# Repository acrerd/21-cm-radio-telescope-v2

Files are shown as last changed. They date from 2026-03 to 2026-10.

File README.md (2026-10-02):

# SRT Motor Driver

A complete control system for a Small Radio Telescope (SRT) for 21cm hydrogen line observations at Acre Road Observatory, Glasgow.

## System Overview

The system consists of four integrated components:

1. **Arduino Due** - Low-level motor control, position tracking, limit switches, current sensing
2. **WT32-ETH01** - Network interface (Ethernet + WiFi), web UI, Stellarium integration, RA/Dec to Alt/Az coordinate transforms
3. **H1 Receiver** - GNU Radio SDR application for 21cm hydrogen line data acquisition
4. **Observation Scheduler** - Web-based scheduler that coordinates telescope pointing and data recording

```
+------------------+     +----------------------+
|   Stellarium     |     |  Observation         |
|   (TCP:10001)    |     |  Scheduler           |
+--------+---------+     |  (HTTP:5000)         |
         |               |                      |
         |               |  - Schedule obs      |
         |               |  - Point telescope   |
         |               |  - Start/stop SDR    |
         |               +----------+-----------+
         |                          |
         |    HTTP API              | Subprocess
         |    (point telescope)     | (start receiver)
         |                          |
+--------+----------+      +--------+-----------+
|                   |      |                    |
|   WT32-ETH01      |      |   H1 Receiver      |
|    Controller     |      |   (GNU Radio)      |
|                   |      |                    |
|  - Ethernet/WiFi  |      |  - Ettus B200 SDR  |
|  - Web UI (:80)   |      |  - FFT processing  |
|  - Coord convert  |      |  - HDF5 output     |
|  - NTP time sync  |      |  - Live display    |
+--------+----------+      +--------------------+
         |
    UART (Serial)
         |
+--------+----------+
|                   |
|   Arduino Due     |
|                   |
|  - Motor PWM      |
|  - Encoders       |
|  - Limit switches |
|  - Current sense  |
+--------+----------+
         |
    Motors/Mount
         |
+--------+----------+
|                   |
|   3.0m Dish       |
|   1420 MHz Feed   |
|                   |
+-------------------+
```

### Data Flow

1. **Scheduling**: User creates observation schedule via web UI (target, time, duration, integration time); the receiver's tuning is fixed, not set per observation
2. **Telescope Control**: At scheduled time, scheduler sends HTTP request to ESP32 to point telescope
3. **Coordinate Conversion**: ESP32 converts RA/Dec or Galactic coordinates to Alt/Az
4. **Motor Control**: ESP32 sends target to Arduino Due, which drives motors to position
5. **Data Acquisition**: Scheduler launches GNU Radio receiver to capture 21cm spectrum data
6. **Storage**: Integrated spectra (or, for the pulsar, millisecond band power) saved to HDF5 files with timestamps and metadata

## Hardware

### Arduino Due
- **Microcontroller:** Arduino Due (ARM Cortex-M3)
- **Motors:** DC motors with H-bridge drivers
- **Position sensing:** Reed switch encoders (0.5° resolution)
- **Current sensing:** ACS712 hall-effect sensors
- **Limit switches:** Altitude ~0°, Azimuth ~0° and ~355°

### WT32-ETH01

- ESP32 module with built-in LAN8720 Ethernet PHY
- Native 100 Mbps Ethernet (RJ45 connector)
- WiFi 802.11 b/g/n (simultaneous with Ethernet)
- Connects to Due via UART serial (IO4/IO14)
- mDNS hostname `srt-controller.local`
- Wired controller web UI at `http://192.168.50.120/`, on a private point-to-point
  Ethernet link to the observatory computer (not the observatory LAN)
- Ethernet OTA firmware updates after the first serial flash

### Wiring: WT32-ETH01 to Arduino Due

| WT32-ETH01 | Arduino Due | Function |
|---|---|---|
| IO4 | Pin 19 (RX1)| ESP32 TX -> Due RX |
| IO14 | Pin 18 (TX1)| ESP32 RX <- Due TX |
| GND | GND | Common ground |
| 5V | 5V | Power |

**Note:** IO4/IO14 are used for Due communication. Avoid IO32/IO33 (labelled CFG/485_EN on RS-485 variants). See [WT32-ETH01 Migration Guide](docs/WT32_ETH01_MIGRATION.md) for details.

---

## Installation

### Prerequisites

- [PlatformIO](https://platformio.org/) (VS Code extension or CLI)

### 1. Arduino Due Firmware

```bash
cd 21-cm-radio-telescope-v2

# Build and upload
pio run -e due -t upload

# Monitor serial output
pio device monitor -b 115200
```

### 2. WT32-ETH01 Controller

```bash
cd 21-cm-radio-telescope-v2/esp32_controller_arduino

# First flash or recovery with temporary FT232 programmer
pio run -e wt32-eth01 --target upload

# Routine Ethernet OTA update after the first serial flash
pio run -e wt32-eth01-ota --target upload
```

The ESP32 controller uses Arduino/PlatformIO.
The OTA target in `esp32_controller_arduino/platformio.ini` is set to the current controller address, `192.168.50.120`.

---

## Configuration

### WT32-ETH01 Settings

Most settings can be changed at runtime via the web interface **Settings** tab:

- Observer location (latitude/longitude)
- Mount software limits (azimuth/altitude ranges)
- Home position
- Update tolerance (position deadband)
- WiFi AP name and password
- Ethernet IP (DHCP or static)

Settings are saved to ESP32 flash (NVS) and persist across reboots.

Compile-time defaults are in `esp32_controller_arduino/src/config.h`:

```cpp
// WiFi Access Point
#define WIFI_AP_SSID "SRT_Controller"
#define WIFI_AP_PASSWORD "radio1420"

// Serial pins to Arduino Due (WT32-ETH01)
#define DUE_UART_TX 4
#define DUE_UART_RX 14

// Observer location (for coordinate conversion)
#define OBSERVER_LAT 55.902426
#define OBSERVER_LON -4.307865
```

### Arduino Due Pin Assignments

| Function | Pin |
|---|-----|
| Az PWM | 8 |
| Az Direction | 9 |
| Alt PWM | 10 |
| Alt Direction | 11 |
| Az Encoder | 12 |
| Alt Encoder | 13 |
| Az Current | A1 |
| Alt Current | A0 |
| Serial1 TX | 18 |
| Serial1 RX | 19 |

---

## Usage

### Connecting to the Web Interface

#### Option 1: Direct WiFi (always available)
1. Connect to WiFi: `SRT_Controller` (password: `radio1420`)
2. Browse to: `http://192.168.4.1`

#### Option 2: Wired Controller, Hostname, or Your Network
1. From the observatory computer, browse directly to: `http://192.168.50.120/`
   (reachable over the private link only — see below for remote access)
2. If mDNS is supported, `http://srt-controller.local/` should also resolve
3. If the controller joins a different network, connect to the AP first
4. Go to **WiFi** tab, click **Scan**
5. Select your network and enter password
6. Browse to the hostname or the new IP

Credentials are saved and the ESP32 auto-reconnects on boot. The AP stays active as fallback.

#### Option 4: Remotely, over an ssh tunnel

The controller is on a private link and the scheduler binds loopback, so neither
is reachable from the network. Reach them *through* the observatory host:

```bash
ssh -L 8080:192.168.50.120:80 -L 5000:127.0.0.1:5000 astro@ettus3.astro.gla.ac.uk
```

Then `http://localhost:8080` for the controller and `http://localhost:5000` for
the scheduler. Forward port 5000 even if you only want the controller: its page
fetches the scheduler at `127.0.0.1:5000` for the Sun Scan, Calibration Day and
firmware-update buttons, and through a tunnel that resolves to your own machine.

For applications rather than web pages — Stellarium, VS Code, the receiver GUI —
use `waypipe ssh astro@ettus3.astro.gla.ac.uk <command>`. Full details, including
the WSL2 client requirements, are in
[Observatory Host Setup](docs/OBSERVATORY_HOST_SETUP.md#10-remote-access).

#### Option 3: Direct WiFi Setup for a New Network
1. Connect to the AP first
2. Go to **WiFi** tab, click **Scan**
3. Select your network and enter password
4. Browse to `http://srt-controller.local/` if mDNS is supported, or note the new IP address
5. Connect your computer to same network
6. Browse to the hostname or the new IP

### Web Interface

#### Control Tab

| Section | Controls |
|---|---|
| **Current Status** | Shows Alt, Az, RA/Dec, Galactic coordinates, motor currents, fault state, and tracking target |
| **Quick Targets** | Track Sun or Moon |
| **Actions** | Stop all, pause slewing for 10 seconds, home, homing, reset active faults, Cal On/Off (drives nothing: the noise diode is gone, issue #39) |
| **Axis Mode** | Track both axes, azimuth only at fixed altitude, or altitude only at fixed azimuth |
| **Coordinates** | Direct Alt/Az, RA/Dec (J2000), and Galactic Go To / Track commands |

**Coordinate Systems:**
- **RA/Dec**: Right Ascension (0-24 hours), Declination (-90 to +90 degrees), **J2000 epoch**
- **Galactic**: Galactic longitude l (0-360°), latitude b (-90 to +90°), **J2000 epoch**
- **Alt/Az**: Altitude (0-90°), Azimuth (0-355°)

All equatorial (RA/Dec) coordinates use the **J2000 reference frame**, which is the standard epoch for modern star catalogs and planetarium software like Stellarium. The controller automatically handles precession when converting to Alt/Az for telescope pointing.

**Tracking Modes:**
- **Go To**: Slew to position once (no tracking)
- **Track**: Continuously update position as Earth rotates
- **Axis-only Track**: Follow target azimuth or altitude while holding the other axis fixed
- **Sun/Moon**: Automatically updates coordinates as they move across the sky
- **Galactic Plane**: Tracks the point on the plane (b = 0) nearest the galactic centre that is currently at or above the acquisition altitude (45° by default), then follows it down until the 10° observing horizon parks the dish. The centre itself is never an option from Glasgow — at Dec −28.9° it culminates at 5.2°, below the trees.

#### Network Tab

- **Ethernet**: Hostname, connection status, IP address, MAC address, DHCP/static configuration
- **WiFi Power**: Enable/disable WiFi to save ~100mA (only available when Ethernet connected)
- **WiFi**: Access Point status, station connection status
- **WiFi Config**: Scan and connect to WiFi networks, forget saved credentials

**Network Priority:** Ethernet provides a stable wired connection for Stellarium. WiFi can be disabled to save power when using Ethernet only.

**Power Consumption:** System draws ~400mA idle (300-320mA with WiFi disabled).

### Stellarium Integration

1. In Stellarium: **Configuration > Plugins > Telescope Control**
2. Enable and restart Stellarium
3. **Add** telescope:
   - Type: External software or remote computer
   - Host: `192.168.50.120` (or AP/network IP)
   - Port: `10001`
4. Click **Connect**
5. Select any object and press `Ctrl+1` to slew

### Serial Commands (Arduino Due)

Connect via USB at 115200 baud.

#### Motion
| Command | Description |
|---|---|
| `45 180` or `DRIVE 45 180` | Slew to Alt=45°, Az=180° (rounded to the 0.5° pulse grid) |
| `HOME` | Run homing sequence (also run at power-on) |
| `STOP` | Emergency stop. During a homing it aborts the homing into `FAULT_HOMING_ABORTED`: the position is unknown until `RESET` then `HOME` |
| `RESET` | Clear fault; `HOME` afterwards to re-home |

During a homing the Due answers `STATUS` with the live line and refuses every
other command except `STOP` with `Homing: busy - ignored`.

#### Status
| Command | Description |
|---|---|
| `STATUS` | Show current position |
| `CONFIG` | Show configuration |
| `HELP` | List all commands |

#### Calibrator
| Command | Description |
|---|---|

#### Configuration
| Command | Description |
|---|---|
| `SET ALTMIN 0` | Minimum altitude (degrees) |
| `SET ALTMAX 90` | Maximum altitude (degrees) |
| `SET CURRENT 4.5` | Current limit (Amps) |
| `SET RAMPUP 1000` | Acceleration time (ms) |
| `SAVE` | Save to flash |
| `LOAD` | Load from flash |
| `DEFAULTS` | Reset to defaults |

`HELP` lists the rest of the `SET` parameters (hardware limits, home position,
ramps, stall timeout, encoder debounce per axis, azimuth backlash).

#### Replies to the controller

Commands arriving on Serial1 (from the ESP32) are answered there. A drive
target gets `ACK DRIVE <alt> <az>` (the target as rounded to the pulse grid) or
`ERR DRIVE fault|homing|limits`; an unparseable line gets `ERR UNKNOWN <line>`.
The ESP32 re-sends a target left unanswered for 2 s once and reports the counts
as `drive_ack` in `/status`.

#### Status Output Format

The ESP32 parses this positionally; currents are printed to one decimal place. The line ends in a checksum, ` *HH`: the XOR of every character before the ` *`, in hex. It replaced the `Cal:ON|OFF` field on 2026-10-02, when the calibrator was removed (issue #39), and the controller rejects a line whose checksum fails.
```
Alt:45.0 Az:180.0 Ialt:0.2A Iaz:0.2A Status:Ready *7D
Alt:45.0 Az:180.0 Ialt:1.0A Iaz:1.1A Status:Slewing -> Alt:60.0 Az:200.0 *1F
Alt:45.0 Az:180.0 Ialt:0.0A Iaz:0.0A Status:FAULT [Azimuth motor stalled] *00
```

Encoder pulses are counted on the reed switches' rising edge.

---

## Operation

### Startup Sequence
1. Power on both controllers
2. Arduino Due homes automatically (drives to limit switches)
3. ESP32 starts WiFi AP and connects to saved network (if any)
4. ESP32 syncs time via NTP (if internet available)
5. System ready when Due status shows "Ready"

### Time Synchronization
Accurate time is required for coordinate calculations. The ESP32 syncs time automatically:

1. **NTP (primary):** If connected to the internet, time syncs from NTP servers
2. **Browser fallback:** If NTP fails, the web interface automatically sends your browser's time to the ESP32 when you open the page

Time status is shown on the Control tab (e.g., "2024-03-13 14:30:00 UTC (NTP)").

### Tracking Mode
When **Track** is enabled:
- ESP32 continuously converts RA/Dec to Alt/Az using current time
- Updates sent to Due every second
- Mount follows object as Earth rotates

### Safety Features
- **Position limits:** Alt 0-90°, Az 0-355°
- **Limit switches:** Physical stops at extremes
- **Current limiting:** Motors stop on overcurrent
- **Stall detection:** Motors stop if position doesn't change

---

## H1 Receiver & Observation Scheduler

The `receiver_scheduler/` folder contains the data acquisition system for 21 cm hydrogen line observations: the receiver itself, a Flask scheduler with a ten-tab operator page, pointing calibration against the Sun, the beam measured from a Sun drift, a radiometric measurement of the obstructed horizon, the bandpass and gain calibration that turns counts into kelvin, the clocks (Thunderbolt 10 MHz/PPS, NTP), and pulsar mode for PSR B0329+54 with its fold and timing. See [its README](receiver_scheduler/README.md) for the tabs and the files.

Everything in the observing path is **headless** — the observatory is worked over ssh — with one deliberate exception, the console-only receiver GUI button.

### Receiver Prerequisites

The receiver requires **radioconda** (or a GNU Radio installation with UHD support):

```bash
# 1. Install radioconda
# Download from: https://github.com/ryanvolz/radioconda

# 2. Activate the environment
conda activate radioconda

# 3. Install additional Python dependencies
cd receiver_scheduler
pip install -r requirements.txt
```

This installs Flask (web scheduler), ephem (satellite tracking), and pytest (testing). GNU Radio, PyQt5, NumPy, and h5py are provided by radioconda.

### Receiver Components

#### H1 Receiver (`b210_h1_receiver.py`)

GNU Radio-based spectrum analyzer for 21 cm observations:

- **SDR Support:** Ettus B200/B210, RTL-SDR, or demo mode (simulated data)
- **Processing:** Real-time FFT with configurable integration time
- **Display:** Live spectrum plot and waterfall display (PyQtGraph)
- **Output:** HDF5 files with integrated spectra, timestamps, and metadata

```bash
# Run standalone receiver
cd receiver_scheduler
python b210_h1_receiver.py --sdr b210 --gain 30

# Or use demo mode without hardware
python b210_h1_receiver.py --sdr demo
```

#### Observation Scheduler (`h1_web_scheduler.py`)

Tabbed web interface that coordinates telescope pointing and data recording:

- **Scheduler Tab:** Add/edit/clone/delete observations with clash prevention, late-start recovery, preemption, and audio notifications
- **Sun Scan Tab:** Pointing calibration via raster scan of the sun (see below)
- **Horizon, RF calibration, Camera, Simulator, Observe, Guide Tabs:** the horizon archive, bandpass/gain and the Clocks card, the safety camera, the sky simulator, running and plotting observations (including pulsar folds and the PRESTO fold)
- **Configuration Tab:** Persistent settings (controller URL, observer location, the fixed instrument, data folder, receiver Python path, the Sun and pulsar monitors, sound)
- **Log Tab:** Live view of rotating scheduler log
- **Start Receiver:** Starts the B200 receiver manually for warm-up/testing and reports whether the receiver is idle, manually started, or owned by a scheduled observation
- **Coordinate Systems:** Alt/Az, RA/Dec (J2000), Galactic, famous targets, Drift Scan (fixed pointing computed from a source and beam-crossing time), Solar System objects (Sun/Moon), Satellite (TLE), PSR B0329+54 (`pulsar`), Calibration day (`calibration`) and Horizon scan (`horizon`)
- **Standing orders:** the Sun monitor tracks the Sun whenever the telescope is idle, and the pulsar monitor records B0329+54 daily; both off by default, both give way to bookings and to anything started by hand
- **Satellite Tracking:** Fetch TLEs from CelesTrak, compute next pass, track via 1 Hz position updates
- **End Actions:** Stay, Go Home, or Stow telescope after observation
- **Firmware Update:** Requests the local scheduler service to build and upload WT32 firmware over Ethernet OTA

```bash
# Start the scheduler
cd receiver_scheduler
python h1_web_scheduler.py --port 5000    # binds 127.0.0.1 by default

# Open browser to http://localhost:5000
```

On the observatory Linux host, use the desktop launcher **Start SRT Sofware**. It starts the scheduler, detached, and opens `http://192.168.50.120/` in Firefox. VS Code and Stellarium were taken out of it on 2026-10-01; both are started by hand when wanted, and opening the VS Code workspace still runs its scheduler and PlatformIO Serial Monitor tasks. `start_scheduler.sh` reuses an already-serving scheduler rather than starting a second one that would die on the bound port. The launcher runs:

```bash
/home/astro/21-cm-radio-telescope-v2/receiver_scheduler/start_scheduler.sh
```

which starts `h1_web_scheduler.py --host 127.0.0.1 --port 5000` only when nothing is already serving on port 5000. There is deliberately no systemd unit: the scheduler starts from the launcher and should not come up unattended.

The **loopback bind is deliberate**. The scheduler has no authentication, and its
endpoints start observations, take the SDR, rewrite the schedule and flash
controller firmware over OTA — bound to `0.0.0.0` that is an unauthenticated
telescope-control API offered to every network the host is attached to. Nothing
needs the wildcard: the controller's own page fetches the scheduler at
`127.0.0.1:5000` from a browser running on this host, and remote use is over
waypipe, which forwards the display rather than the connection.

The scheduler re-execs itself under the configured receiver Python when needed so GNU Radio, PyEphem, and SDR dependencies come from radioconda. On the observatory machine the receiver Python default is `/home/astro/radioconda/bin/python`.

### Scheduler Configuration

Settings are managed via the Configuration tab in the web interface and persisted in `scheduler_config.json`. Key settings include:

- **Controller URL** — ESP32 address, currently `http://192.168.50.120` (empty to disable telescope control)
- **Controller Fallback URLs** — Additional controller addresses such as `http://srt-controller.local` and `http://192.168.4.1`
- **Observer Location** — Latitude, longitude, elevation (used for satellite pass prediction)
- **Min Elevation** — Minimum elevation for satellite passes (default 10°)
- **Instrument** — The fixed tuning and the pilot, editable here only, with a warning that a change leaves later recordings uncalibrated
- **Data Output Folder** — Where HDF5 files are saved
- **Receiver Python Path** — Path to the radioconda Python executable used by the scheduler and receiver
- **Sun monitor / Pulsar monitor** — `sun_monitor`; `pulsar_monitor`, `pulsar_monitor_window` (`follow` or `clock`), `pulsar_monitor_start`, `pulsar_monitor_hours`
- **Pulsar band** — `pulsar_sample_rate_hz` (32 Msps) and `pulsar_lo_hz` (1413 MHz), in `scheduler_config.json` only
- **Firmware Update Environment** — PlatformIO environment used for WT32 Ethernet OTA uploads

### Observation Workflow

1. **Open Scheduler:** Browse to `http://localhost:5000`
2. **Add Observation:** Click "+ Add Observation"
   - Select coordinate system and enter target (or fetch satellite TLE from CelesTrak)
   - Set start date/time and duration (end time calculated automatically)
   - Set integration time, SDR type, homing first, the horizon check, and end action (stay/home/stow); the instrument is shown, not set
3. **Save Schedule:** Auto-saved with clash prevention; running items are locked
4. **Automatic Execution:** At scheduled time:
   - Homes the mount first if the entry asks
   - Scheduler sends pointing command to ESP32
   - Waits for slew to complete (polls `is_slewing` status)
   - Starts satellite tracking thread if applicable
   - Launches GNU Radio receiver
   - Data saved to HDF5 with observation metadata: `spectra_kelvin` when the bandpass template and gain in force apply, `spectra_linear` (raw counts) when they do not
   - On completion: telescope home/stow if configured
5. **Monitor:** Status bar shows running observation with countdown, or time to next observation when idle

### Sun Scan — Pointing Calibration (`sun_scan.py`)

Determines telescope pointing errors by performing an n×n raster scan centred on the sun. The antenna beam (4.30° FWHM-equivalent, from the main-lobe solid angle of 21.0 sq deg in `beam_calibration.json`) is sampled at each grid point by measuring broadband power, then a 2-D Gaussian is fitted to locate the true peak. The difference between the fitted peak and the assumed sun position gives the pointing correction.

- **Integrated via the Sun Scan tab** in the web scheduler — uses the same observer location, SRT controller URL, and SDR settings as the scheduler
- **Grid:** configurable n×n (default 5×5) with adjustable spacing (default 1.5°, about a third of the beam)
- **Scan pattern:** all rows scan east-to-west with backlash overshoot at each row start
- **Azimuth correction:** grid offsets are treated as cross-elevation sky offsets and mount azimuth commands are expanded by cos(altitude); scans stop with a clear error if any requested grid point would be clipped by mount limits
- **Moving Sun:** Sun position is recomputed before each measurement slew, checked again after hardware motion, and refined when necessary; the saved comparison point is the mid-scan ephemeris
- **Verified movement:** before scanning, the scheduler resolves the reachable controller from the primary/fallback URLs. Each command must reach its requested position within tolerance; rejected commands, telescope faults, a stationary mount, wrong final coordinates, and timeouts stop immediately with a detailed website error. The point counter advances only after a completed measurement.
- **Physical reference and retry:** Calibration Day runs the Due `HOME` sequence before each hardware raster so displayed coordinates are re-established at the physical limits. It automatically re-homes and retries one rejected raster before counting a scan failure. A continuing mismatch between displayed and physical position is a motor, encoder/coupling, or power problem and must not be treated as valid calibration data.
- **Stable B200 acquisition:** one B200 session is held across the complete raster, explicitly on `RX2`, with a short discarded warm-up capture. The standalone receiver cannot start while calibration owns the SDR.
- **Fit quality:** Gaussian peaks outside the measured raster, implausible beam widths, non-finite uncertainty, and poor fits are rejected and displayed as website errors rather than entering the day model
- **Output:** pointing error (ΔAlt, mount ΔAz, sky ΔAz), fitted beam FWHM, scan start/end timestamps, and a two-panel image (measured data + Gaussian fit)
- **SDR backends:** B200/B210, RTL-SDR, or demo mode (simulated Gaussian beam)
- **Standalone usage:**

  ```bash
  python sun_scan.py --n 5 --spacing 1.5 --integration 3.0 --sdr demo
  ```

#### Calibration Day — Pointing Model

Running repeated sun scans over a day fits the mount's pointing model. The base model has four terms:

- **IE, IA** — elevation and azimuth index (constant zero-point offsets)
- **AN** — north-south tilt of the azimuth axis
- **AE** — east-west tilt of the azimuth axis

and two more when the scans can constrain them: **CA** (collimation, the beam not perpendicular to the elevation axis; needs a spread of altitude) and **AZSCALE** (an azimuth scale error; needs 90° of azimuth). Any term can be held at a stored value: after a feed change only IE and CA are refitted.

**Apply to Telescope** POSTs the fitted terms as a document to the controller's `/pointing/apply`. The controller keeps it in its own NVS namespace and applies it in `pointing.cpp` (`trueToDrive`, which also takes NPAE and TF) to every goto, track and manual move, and inverts it for every reported position. The observer position stays the true site; the model is never folded into an effective latitude/longitude, and the operator's offset boxes are not touched.

Calibration Day performs one complete N×N Sun scan per start-to-start interval and saves each successful scan before waiting for the next. The fit needs at least four successful scans; applying it needs 30 degrees of Sun azimuth coverage, a condition number under 10⁴ and significant tilt terms. It weights scans by their fitted uncertainties, leaves out scans taken with the Sun behind the measured horizon, and reports parameter uncertainty and residual RMS. Hardware, scan, fit, and apply errors appear in the receiver website; three consecutive scan failures stop a calibration day.

To run a calibration day:
- **From the scheduler:** add a "Calibration Day (Sun Scan)" observation with a start time before sunrise and a long duration (e.g. 12 hours). The scheduler waits for sunrise, runs scans at the configured interval, and stops at sunset.
- **From the Sun Scan tab:** use the Calibration Day controls to start/stop manually, fit the model, and apply corrections.
- **Recommended:** 6–8 scans spread over several hours for good azimuth coverage. Spring–autumn gives best results.

### Output Data Format

Every recording goes in `receiver_scheduler/data/observations/`, named for when it was made and what the mount was doing — and nothing else, because everything else is inside the file:

```
20260825_192937_drift.h5     the dish was parked; the sky drifted through the beam
20260825_201455_track.h5     the mount followed the source
20260825_143012_manual.h5    started at the console; nobody commanded the mount
20260926_203116_pulsar.h5    a PSR B0329+54 entry: millisecond band power, not spectra
```

`track` and `drift` describe the mount rather than the box the entry was typed into: an alt/az observation is a **drift** scan, because the scheduler parks the dish and leaves tracking off. Calibration days and horizon scans write their own products (`pointing_data.json`, `horizon_profiles/`), not recordings.

A pulsar recording holds `power` (N × 1 float32: by default one 32 MHz channel at 1413 MHz, summed per millisecond), `frequency_hz`, `time_marks` and `overflow_marks`, with the time source (`time_source` pps/host) and the calibration in force (`cal_*`) as attributes; see [the receiver README](receiver_scheduler/README.md#pulsar-recordings) and `docs/PULSAR_PROCESSING.tex`.

Since issue #27 the B200 records with a **fixed instrument** (LO 1418.905752 MHz,
8 Msps, gain 20 dB, set in `tuning.py`) and every file carries **two products** —
an H I sub-band and a whole-band continuum product — readable while it is still
being written (HDF5 SWMR):

```
20260826_184209_drift.h5
├── frequency_hz            # H I sub-band axis (Hz), 845 channels
├── spectra_kelvin          # H I product, antenna temperature (K)  -- when calibrated
│   or spectra_linear       #             raw power (counts)         -- when not
├── frequency_hz_wide       # Continuum product axis, 1024 ch over 8 MHz
├── spectra_wide_kelvin     # Continuum product (K or counts)
│   or spectra_wide_linear
├── bandpass_correction(_wide), bandpass_valid(_wide)  # per-channel correction applied
├── timestamps              # Unix time at the centre of each record
├── integration_times       # Actual integration per record
├── overflows               # UHD overflows during the record
└── attrs:
    ├── spectra_units, spectra_wide_units            # "K" or "counts", per product
    ├── instrument, h1_band_hz, continuum_band_hz    # the fixed instrument and its bands
    ├── applied_gain_counts_per_k, applied_t_sys_k   # to reverse the calibration
    ├── bandpass_template(_wide), gain_calibration   # the full calibration, as JSON
    ├── beam_fwhm_deg, effective_area_m2, site_*     # measured beam and surveyed site
    ├── sdr_type, center_freq_hz, sample_rate_hz, gain_db, created
    ├── obs_name, comment, observation_mode          # "track", "drift" or "manual"
    ├── coord_system        # altaz, radec, galactic, object, drift, or satellite
    ├── drift_crossing_time, drift_crossing_offset_deg   # drift scans: parked-beam crossing
    ├── homed_first, homing_count_error_*_deg        # if homed first: the raw stop counters (offset + drift)
    ├── clock_source, clock_ref_locked, reference_*  # the 10 MHz in use; the Thunderbolt's state
    ├── pointing_terms                               # the pointing model in force
    └── ...                 # target coordinates, TLE, schedule times
```

**The dataset name is the units.** If the bandpass template and gain in force applied to the tuning, the spectra were converted at write time and live under `spectra_kelvin`; otherwise they are raw counts under `spectra_linear`. Asking for the wrong name raises `KeyError` instead of quietly handing back the other scale. Nothing is lost by calibrating on write — the correction, the gain and the system temperature all travel in the file, so the raw counts are one line away:

```python
raw = (spectra + attrs['applied_t_sys_k']) * attrs['applied_gain_counts_per_k'] * bandpass_correction
```

If the receiver frequency, sample rate, or FFT size changes during a run, the receiver closes the current file and opens a new one so every file stays internally consistent. The new file is named like any other; the reason for the split is recorded in its `segment` and `segment_reason` attributes.

See `notebooks/read_h1_data.ipynb` for a complete analysis example, and
`notebooks/solar_flux_scallop.ipynb` for the whole reduction of a solar track.

---

## Troubleshooting

| Problem | Solution |
|---|---|
| Can't connect to controller web UI | Try `http://192.168.50.120/`, then `http://srt-controller.local/`, then AP mode at `192.168.4.1` |
| Can't connect to scheduler web UI | Start `h1_web_scheduler.py` and open `http://localhost:5000` on that host |
| Motors don't move | Check Due serial for FAULT status, verify homing completed |
| Position incorrect | Run `HOME` command, check limit switches |
| Stellarium won't connect | Verify IP and port 10001, check ESP32 is running |
| Coordinates don't match sky | Check observer lat/lon, verify NTP time sync |

---

## File Structure

```
21-cm-radio-telescope-v2/
├── platformio.ini          # PlatformIO build config (Arduino Due)
├── README.md               # This file
│
├── src/                    # Arduino Due firmware
│   └── main.cpp            # Motor control, encoders, limits
│
├── include/
│   └── config.h            # Due pin assignments, defaults
│
├── esp32_controller_arduino/   # WT32-ETH01 Arduino/PlatformIO
│   ├── platformio.ini          # ESP32 build config
│   ├── test/                   # Host unit tests: coordinates, pointing (pio test -e native)
│   └── src/
│       ├── main.cpp            # Main application, tracking loop
│       ├── config.h            # Default settings
│       ├── settings.cpp/h      # Runtime settings with NVS persistence
│       ├── wifi_manager.cpp/h  # WiFi AP/STA management
│       ├── web_server.cpp/h    # HTTP server & web UI
│       ├── srt_serial.cpp/h    # Serial protocol to Due
│       ├── coordinates.cpp/h   # RA/Dec/Galactic <-> Alt/Az
│       ├── pointing.cpp/h      # True <-> drive frame: refraction and the pointing model
│       ├── diag.cpp/h          # Reset-surviving diagnostics record, loop watchdog, /diag
│       ├── sync.cpp/h          # Cross-task locking between loopTask and async_tcp
│       ├── stellarium.cpp/h    # Stellarium telescope protocol
│       ├── state.h             # Global state structure
│       └── index_html.h        # Embedded web interface
│
├── receiver_scheduler/     # Observation scheduling & data acquisition
│   ├── h1_web_scheduler.py # Flask scheduler: routes, schedule, observing state
│   ├── web/                # The operator page as static files (index.html,
│   │                       #   app.css, js/ - fifteen scripts, one per tab plus five shared)
│   ├── b210_h1_receiver.py # GNU Radio receiver (B200/RTL-SDR); spectra or pulsar mode
│   ├── sun_scan.py         # Sun raster, pointing model, calibration day
│   ├── beam_scan.py        # The beam's solid angle from a two-hour Sun drift
│   ├── horizon_scan.py     # Radiometric horizon measurement
│   ├── rf_calibration.py   # Counts to kelvin: gain, T_sys, velocity shift
│   ├── bandpass.py         # The measured instrument response
│   ├── pilot.py            # The B200's TX as gain/passband reference (off by default)
│   ├── tuning.py           # The fixed instrument: LO, rate, gain, the two bands
│   ├── drift_park.py       # Park a drift scan on the drive grid
│   ├── drift_fit.py        # Total-power fit of a drift scan vs the model curve
│   ├── scallop.py          # Tracking scallop removed from a tracked compact source
│   ├── observation_plot.py # Finished observations, in kelvin and LSR velocity
│   ├── observatory.py      # Site and beam - plumbing; numbers in instrument.py
│   ├── observation_files.py # Where a recording goes and what it is called
│   ├── solar_reference.py  # RSTN/F10.7 reference fluxes from NOAA SWPC
│   ├── pulsar_fold.py      # B0329+54: fold at the absolute phase, S/N, flux, PRESTO
│   ├── pulsar_toa.py       # TOAs against the EPN template; the .tim files
│   ├── pint_tools.py       # PINT residuals and fits (run in the pint env)
│   ├── sigproc_export.py   # Pulsar recording -> SIGPROC .fil for PRESTO
│   ├── clocks.py           # Thunderbolt, host NTP and controller clock; stability
│   ├── thunderbolt.py      # The Thunderbolt's TSIP status monitor
│   ├── plot_backend.py     # Agg unless in a Jupyter kernel
│   ├── data/observations/  # Every recording: <date>_<time>_<track|drift|pulsar|manual>.h5
│   ├── horizon_profiles/   # Every horizon scan, by date, one chosen
│   ├── pulsar_timing/      # b0329.tim, b0329_segments.tim, stored profiles
│   └── README.md           # Receiver/scheduler documentation
│
├── notebooks/              # Worked data-reduction examples, run from anywhere
│   ├── read_h1_data.ipynb  # Open a recording, see what is in it, plot it
│   └── solar_flux_scallop.ipynb # A solar track: band power -> SFU, scallop removed
│
├── astro_simulator/        # Sky simulator (HI4PI + continuum)
│   ├── instrument.py       # Surveyed site, measured beam - the one copy
│   ├── horizon_store.py    # The dated horizon archive, and the rule for using it
│   └── web/                # Browser build, served by the scheduler at /simulator/
│
└── docs/
    ├── SRT_DRIVE_MANUAL.md         # Arduino Due firmware manual
    ├── ESP32_CONTROLLER.md         # ESP32 controller manual
    ├── WT32_ETH01_MIGRATION.md     # WT32-ETH01 setup guide
    ├── OBSERVATORY_HOST_SETUP.md   # building the host and its private controller link
    ├── HOST_REBUILD.md             # rebuilding the observatory computer; host/ snapshots
    ├── CALIBRATION.md              # how the telescope is calibrated
    └── PULSAR_PROCESSING.tex       # pulsar mode: recording, fold, TOAs, timing
```

---

## Documentation

- [SRT Drive Manual](docs/SRT_DRIVE_MANUAL.md) - Arduino Due firmware reference
- [ESP32 Controller Manual](docs/ESP32_CONTROLLER.md) - WT32-ETH01 controller and API reference
- [WT32-ETH01 Setup Guide](docs/WT32_ETH01_MIGRATION.md) - Hardware setup and wiring
- [Observatory Host Setup](docs/OBSERVATORY_HOST_SETUP.md) - Building a new observatory computer: second Ethernet card, private link to the controller, firewall and scheduler
- [Host Rebuild](docs/HOST_REBUILD.md) - Everything needed to replace the observatory computer, including the files git does not hold; environment snapshots in `docs/host/`
- [Calibration](docs/CALIBRATION.md) - What the bandpass template, gain fit, pilot and beam each measure, the order they are applied in, and what is still uncalibrated
- [Pulsar Processing](docs/PULSAR_PROCESSING.tex) - Pulsar mode for B0329+54: recording, fold, TOAs and timing
- [Receiver & Scheduler](receiver_scheduler/README.md) - H1 receiver and observation scheduler

## License

MIT License - Acre Road Observatory, University of Glasgow

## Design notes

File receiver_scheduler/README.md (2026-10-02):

# Hydrogen Line (21cm) Receiver

A real-time spectrum analyzer for observing the hydrogen line at 1420.405 MHz using software-defined radio. Features a PyQtGraph GUI with live spectrum and waterfall displays, continuous data logging to HDF5, and a web-based observation scheduler.

## Overview

This receiver is designed for radio astronomy observations of neutral hydrogen (HI) emissions at 1420.405 MHz. It provides:

- Real-time spectrum display with integrated averaging
- Waterfall/spectrogram visualization
- Continuous data recording to HDF5 format
- Support for multiple SDR platforms (Ettus B200/B210, RTL-SDR)
- Demo mode for testing without hardware
- Web-based scheduler for automated observations

## Files

| File | Description |
|---|---|
| `h1_web_scheduler.py` | The Flask scheduler: routes, the schedule, and the observing state machine |
| `web/` | The operator page as static files — `index.html`, `app.css`, and fifteen scripts under `js/`: one per tab (ten), plus `state.js` (first), `shared.js`, `help.js`, `clock.js` and `boot.js` (last). Read per request, so editing them needs a browser refresh and not a scheduler restart |
| `b210_h1_receiver.py` | The receiver. `--headless` for observing, a Qt window for warm-up at the console; `H1_MODE=pulsar` records the pulsar band instead of spectra |
| `sun_scan.py` | Sun raster, pointing-model fit, calibration day |
| `horizon_scan.py` | Radiometric horizon measurement, and the Stellarium landscape export |
| `rf_calibration.py` | Counts to kelvin: gain, system temperature, and the velocity shift (held at zero on the locked Thunderbolt reference) |
| `beam_scan.py` | The beam from a two-hour Sun drift: main-lobe solid angle integrated directly, adopted into `beam_calibration.json` only if the scan passes |
| `scallop.py` | The tracking scallop, fitted from a tracked Sun/Moon/Jupiter run (or carried from the last quiet one) and taken out of the source term |
| `pulsar_fold.py` | B0329+54: the streaming fold at the absolute phase, the matched S/N, the flux scale, and the PRESTO fold |
| `pulsar_toa.py` | Times of arrival from the fold against the EPN template; writes `pulsar_timing/b0329.tim` (nights) and `b0329_segments.tim` (4 h checks) |
| `pint_tools.py` | The PINT side of timing, run by subprocess in the `pint` environment, never radioconda |
| `sigproc_export.py` | A pulsar recording as a SIGPROC `.fil` for PRESTO, overflow gaps filled so every row sits on the time grid |
| `clocks.py` | The three clocks (Thunderbolt, this computer's NTP, the controller's) judged in one place; the modified Allan deviation and its transition |
| `thunderbolt.py` | Reads the Thunderbolt's TSIP status in a thread; the one reader of its serial port, and the queue for commands to it |
| `plot_backend.py` | `use_headless()`: Agg for scripts and the scheduler, left alone in a Jupyter kernel |
| `bandpass.py` | The measured instrument response: one template per product, and whether it applies to a given tuning |
| `tuning.py` | The **fixed instrument** — LO, sample rate, gain and the two product bands — shared by the receiver and the scheduler; the older LO-offset planner is kept for the console window |
| `drift_park.py` | Parks a drift scan on the drive grid: the controller's transform in Python, validated against its own reports |
| `drift_fit.py` | The total-power fit of a drift scan against the predicted drift curve (continuum band only) |
| `observation_files.py` | Where recordings go and what they are called |
| `observation_plot.py` | Reads a recording (live or finished, either product, always as counts) and renders it, in kelvin and on an LSR velocity axis |
| `observatory.py` | Where the telescope is and how big its beam is — plumbing only; the numbers live in `astro_simulator/instrument.py` |
| `solar_reference.py` | The professional solar flux quoted beside ours: reads NOAA SWPC's hourly RSTN local-noon file, keeps a dated history in `data/`, never waits on the network |
| `pilot.py` | The **pilot** (issue #30): the B200's own TX as the gain and passband reference — a full-band comb burst every N-th record plus a continuous carrier for the fast wobble; the frames, the flat rectangular reference, the per-burst response, the power level and tilt, the delay-filtered passband correction and its reversal. GNU-Radio-free so the scheduler can reduce with it. See `docs/CALIBRATION.md` |
| `ad9361_filters.py` | **Not imported at runtime.** A standalone account of the B200's decimation-filter chain and the passband shape it implies, run by hand; `bandpass.py`'s docstring cites its result (about 4% of the measured response). Kept as the reasoning behind measuring the bandpass rather than modelling it |
| `investigations/lo_shape_*.py`, `investigations/freq_switch_demo.py` | One-off investigations from the LO-placement work, not imported by anything, kept for their reasoning |
| `tests/page_sources.py`, `tests/conftest.py` | Test plumbing: collects the operator page and every script it loads; keeps the suite out of the observatory's records |
| `../tools/` | Hardware-side scripts, none of them part of the observing path: `due_emulator.py` (bench emulator of the Due's serial protocol for ESP32 work), `az_switch_probe_capture.py` (drives the Due's `PROBE` command and records the azimuth limit switch's reed/current trace, issue #32), `homing_scan_experiment.py` (home from the Sun's position then Sun scan, repeated, for homing-repeatability tests) |

The JSON files beside the code are the scheduler's state, not code; `data/` holds recordings, plots and diagnostic archives; `horizon_profiles/`, `pointing_models/` and `beam_calibrations/` are the dated archives of measurements. The calibrations (`gain_calibration.json`, `bandpass_template*.json`, `beam_calibration.json`), `pointing_data.json`, the horizon and pointing archives and `pulsar_timing/` are tracked by git; `h1_schedule.json`, `scheduler_config.json`, `pointing_model.json`, `last_observation.json`, `scallop_reference.json` and `data/` are not (`docs/HOST_REBUILD.md` lists what to save).

### State the scheduler keeps

| File | Description |
|---|---|
| `h1_schedule.json` | The observation schedule |
| `scheduler_config.json` | Local configuration (auto-generated, gitignored) |
| `scheduler.log` | Rotating log — the operational record of what the telescope did |
| `bandpass_template.json`, `bandpass_template_wide.json` | The measured bandpass in force, one per product |
| `gain_calibration.json` | The gain and system temperature in force, and the velocity shift (zero, and never carried, when fitted on the locked reference) |
| `beam_calibration.json` | The measured beam in force (21.0 sq deg, 4.30° FWHM-equivalent since 2026-09-25) |
| `scallop_reference.json` | The scallop parameters carried from the last quiet solar track |
| `pulsar_timing/` | `b0329.tim`, `b0329_segments.tim` and the stored fold of every pulsar recording (`profiles/`) |
| `pointing_data.json` | Every Sun scan on file, which the pointing model is fitted from |
| `horizon_profiles/` | Every horizon scan, kept by date, with `active.json` naming the one in force |
| `horizon_profile.json` | A mirror of whichever horizon profile is active, for older readers |
| `last_observation.json` | Points at the last run, so the Observe tab survives a restart |
| `requirements.txt` | Python package dependencies |
| `start_srt_software.sh` | The desktop launcher: starts the scheduler and opens the controller in Firefox |
| `start_platformio_monitor.sh` | Single-instance serial monitor with device wait and lock retry handling |
| `SRT Software.code-workspace` | VS Code workspace with automatic scheduler and serial-monitor tasks |

### Tests

`cd receiver_scheduler && python -m pytest` — about 540 tests (2026-09-14). `conftest.py` keeps the suite out of the observatory's records: it detaches the loggers from `scheduler.log` and redirects the last-observation pointer, because several tests run the real `stop_observation`. No test may open the B200; stub `sun_scan._B210PowerMeter` if you need the non-demo path. One test, `TestFlaskAPI::test_post_config`, reaches the live controller and fails on the observatory host for that reason alone.

| File | Covers |
|---|---|
| `test_scheduler.py` | Scheduling, the observation lifecycle, preemption, the API, homing judgements, expired bookings, the per-entry gain override |
| `test_scheduler_state.py` | That the names describing a running observation agree with each other |
| `test_exclusion.py` | That only one thing at a time owns the SDR and the mount |
| `test_sun_scan.py` | Raster geometry, the pointing fit, obstruction handling |
| `test_horizon_scan.py` | Strip scanning, partial saves, deriving clearance afterwards |
| `test_horizon_store.py` | The dated archive, choosing which profile is in force, window trimming |
| `test_rf_calibration.py` | Gain and T_sys fitting, RFI rejection, the LO artefact |
| `test_rf_goto.py` | Sending the dish to the bandpass field, and refusing to while something else holds it |
| `test_bandpass.py`, `test_tuning.py` | The instrument response and the tuning plan |
| `test_fixed_instrument.py` | The fixed instrument: one tuning, two products per recording, and the legacy dataset names |
| `test_self_contained.py` | That a recording carries everything needed to re-reduce it, and that kelvin written at record time reverse exactly |
| `test_velocity_frame.py` | The LSR correction and the clock offset |
| `test_drift_park.py` | Parking a drift scan on the drive grid, against the controller's own reported positions |
| `test_drift_plot.py` | The drift-scan plot: total power per record, the recorded crossing marked |
| `test_live_plot.py` | The live plot on the Observe tab and the route table it is served from |
| `test_solar_recording_plot.py` | A solar track's recording drawn as flux against the clock, the way its live view was |
| `test_solar_reference.py` | The RSTN reference flux: parsing NOAA's file, the history, never waiting on the network |
| `test_pilot.py` | The pilot: the flat rectangular reference (and why the windowed one fails at the band edges), detection and non-detection (the TX unplugged), the framing offset, level and tilt as power quantities, the ripple recovered by averaging bursts and refused from too few, the kelvin write and its exact reversal with the burst records dropped, the per-entry switch and the endpoints; a demo-source flowgraph run that gates a switched burst |
| `test_sun_monitor.py`, `test_pulsar_monitor.py` | The two standing orders: when they run, what they yield to, and every manual start path that must stop them |
| `test_pulsar.py`, `test_pulsar_toa.py`, `test_pulsar_timing_update.py` | The fold, the TOAs and the `.tim` files, and the automatic timing update after a pulsar run |
| `test_beam_scan.py`, `test_scallop.py` | The beam from a Sun drift (including the drift angle's sign), and the scallop fit and its carried reference |
| `test_thunderbolt.py`, `test_clock_stability.py` | TSIP decoding, and the stability plot's deviation and transition |
| `test_page_structure.py`, `test_page_javascript.py` | That the operator page has not lost an element, a handler, or a route |

## Hardware Requirements

### Supported SDRs

| SDR | Frequency Range | Sample Rate | Notes |
|-----|---|---|---|
| Ettus B200/B210 | 70 MHz - 6 GHz | Up to 56 MHz | Recommended for best performance |
| RTL-SDR (R820T/R820T2) | 24 - 1766 MHz | Up to 2.4 MHz | Budget option, adequate for H1 |

**Note:** RTL-SDR dongles with the older E4000 tuner cannot reach 1420 MHz. Ensure you have an R820T or R820T2 tuner.

### Antenna

A suitable antenna for 1420 MHz is required. Common options include:
- Horn antenna
- Parabolic dish with appropriate feed
- Helical antenna
- Yagi-Uda antenna

### Optional: Low Noise Amplifier (LNA)

An LNA at the antenna improves sensitivity significantly. Look for:
- Frequency coverage including 1420 MHz
- Low noise figure (< 1 dB ideal)
- Adequate gain (20-30 dB typical)

## Software Requirements

### Radioconda

This project uses [Radioconda](https://github.com/ryanvolz/radioconda), a conda distribution that includes GNU Radio and SDR tools.

#### Installation

1. Download Radioconda from: https://github.com/ryanvolz/radioconda/releases

2. Install Radioconda:
   - **Windows:** Run the installer executable
   - **Linux/macOS:** Run the shell script installer

3. Activate the environment:
   ```bash
   conda activate radioconda
   ```

4. Install additional dependencies:
   ```bash
   pip install -r requirements.txt
   ```

   This installs Flask (web scheduler), ephem (satellite tracking), and pytest (testing).

### Included with Radioconda

- GNU Radio (gr-uhd, gr-osmosdr)
- PyQt5 / PyQtGraph
- NumPy
- h5py

These cannot be pip-installed and must come from Radioconda.

### SDR Drivers

#### Ettus B200/B210
- Install UHD drivers from [Ettus Research](https://files.ettus.com/binaries/uhd/latest_release/)
- Download FPGA images:
  ```bash
  uhd_images_downloader
  ```

#### RTL-SDR
- Drivers are typically included with Radioconda
- On Windows, you may need [Zadig](https://zadig.akeo.ie/) to install WinUSB driver

## Usage

### Running the Receiver Directly

```bash
# Activate Radioconda environment
conda activate radioconda

# Run with Ettus B200 (default)
python b210_h1_receiver.py

# Run with RTL-SDR
python b210_h1_receiver.py --sdr rtlsdr

# Run in demo mode (no hardware required)
python b210_h1_receiver.py --sdr demo
```

### Command Line Options

```
usage: b210_h1_receiver.py [-h] [--sdr {b210,rtlsdr,demo}] [--gain GAIN]
                           [--sample-rate SAMPLE_RATE] [--headless]

Hydrogen Line (21cm) Receiver

optional arguments:
  -h, --help            show this help message and exit
  --sdr, -s {b210,rtlsdr,demo}
                        SDR type (default: b210, which is the B200)
  --gain, -g GAIN       RF gain in dB (default: 30 for both SDRs)
  --sample-rate, -r SAMPLE_RATE
                        Sample rate in Hz (default: 2.4e6 for B200, 2.048e6 for RTL-SDR)
  --headless            Record without any GUI: no Qt, no display needed. This is
                        how scheduled and Observe-tab observations run.
```

`--gain` and `--sample-rate` set the console window only. A headless run records with
the fixed instrument (from `H1_INSTRUMENT` when the scheduler starts it) and
ignores both.

### Examples

```bash
# B200 with higher sample rate for wider bandwidth
python b210_h1_receiver.py --sdr b210 --sample-rate 5e6

# RTL-SDR with adjusted gain
python b210_h1_receiver.py --sdr rtlsdr --gain 45

# Demo mode for testing
python b210_h1_receiver.py --sdr demo
```

## Web Scheduler

The web scheduler provides a browser-based interface for managing and automating observations.

### Starting the Scheduler

On the observatory Linux host, double-click **Start SRT Sofware**. The launcher:

1. Starts `h1_web_scheduler.py` under radioconda on port 5000 through `start_scheduler.sh`, detached, unless one is already serving. Its console output goes to `/tmp/srt-scheduler-console.log`; the operational record is `scheduler.log` as always.
2. Opens the live controller at `http://192.168.50.120/` in Firefox.

VS Code and Stellarium were taken out of the launcher on 2026-10-01. Opening the VS Code workspace by hand still runs the scheduler and PlatformIO Serial Monitor tasks (the monitor waits for `/dev/ttyACM0`, prevents duplicate monitors, and retries temporary exclusive-lock failures); Stellarium is started by hand and its telescope is configured at `192.168.50.120:10001`. Launcher diagnostics are written to `/tmp/srt-software-launcher.log`.

The scheduler start runs:

```bash
/home/astro/21-cm-radio-telescope-v2/receiver_scheduler/start_scheduler.sh
# -> h1_web_scheduler.py --host 127.0.0.1 --port 5000, only if nothing is already serving
```

For a manual terminal start:

```bash
conda activate radioconda
python h1_web_scheduler.py
```

Then open http://localhost:5000 in your browser.

The scheduler points at the current controller web UI by default: `http://192.168.50.120`. The AP fallback remains `http://192.168.4.1`.

### Web Interface Tabs

Ten tabs. Everything that produces data you keep is headless; the one
deliberately graphical path is the **Start receiver GUI (console only)** button
in the status bar, which opens the receiver's Qt window on the observatory
machine for warm-up and checking the band. It will fail over ssh, and that is
correct rather than broken.

| Tab | For |
|-----|-----|
| **Scheduler** | Booking observations, and what is running now |
| **Sun Scan** | Pointing calibration: a raster on the Sun, the model fit, and the calibration day that repeats it; *Start beam drift* runs the two-hour Sun drift that measures the beam |
| **Horizon** | Measuring the obstructed horizon, choosing which measured profile is in force, and exporting it to Stellarium |
| **RF calibration** | A **Progress** panel at the top for the job running; the two bandpass templates (measured live, with a *Go to Lockman Hole* button, or fitted from a recording on disk); the counts-to-kelvin gain, with suggested targets screened against the measured horizon; the pilot's status; and the **Clocks** card — the Thunderbolt (lock, disciplining, satellites and their signal levels, antenna position and cable delay), this computer's NTP, the controller's clock and its offset from this one, active warnings only, and an on-demand stability plot of the Thunderbolt's PPS record with the transition read off it |
| **Camera** | The safety camera watching the dish: snapshots, and live video at a chosen frame rate |
| **Simulator** | The sky simulator, served from the scheduler so the two share an origin; its *Schedule* button books (or starts) an observation |
| **Observe** | Running an observation now, and looking at any recording (see below) |
| **Configuration** | Site, controller, horizon, camera and receiver settings; the fixed instrument and the pilot, editable here only, with a warning; the Sun monitor and the pulsar monitor |
| **Log** | The operational record |
| **Guide** | How to operate the telescope, and the astronomy behind it |

Only one of the Sun scan, calibration day, horizon scan, RF calibration, a
scheduled observation, or a hand-started receiver may hold the B200 and the
mount at once; whichever is asked for second is refused with the reason.

#### Observe Tab

Runs an observation immediately (*Start Now*), or hands one to the schedule
form (*Send to Scheduler*). Four types:

- **Spectrum (tracked)** — the dish follows a galactic direction
- **Drift scan** — the dish is parked and the source crosses the beam, transiting at the mid-point
- **Solar track (flux monitor)** — the dish follows the Sun, plotting flux in
  solar flux units live while the spectra record as usual. The plot bins the
  whole run rather than its tail and updates at the rate records appear. When
  the run ends the live trace comes down and the finished recording is plotted
  in its place.
- **Solar drift** — the dish parks where the Sun will be at the mid-point and
  the Sun drifts through the beam (a drift entry in the `object` frame)

Drift scans get the same live plot, in antenna temperature: the time axis is
the observation's own start-to-stop window, fixed from the moment it begins,
with the beam-crossing time marked — so the trace fills in from the left and a
source should peak on the dashed line. The plotted number is the band median,
i.e. the continuum level: it follows a broadband source through the beam but is
nearly blind to a narrow line, so an H I drift scan can show little here while
recording the line perfectly well. The first point lands roughly one
integration after the slew finishes — a 60 s average cannot exist sooner — so
a shorter integration per record gives faster feedback (the plot bins records
down anyway). Expect the trace to wander a few tenths of a kelvin beyond the
radiometer floor: band-integrated total power is limited by receiver gain and
atmosphere stability (measured 2.3×10⁻⁴ of T_sys per minute), not by thermal
noise, and an absolute offset of some kelvin means the gain calibration is
stale — it drifts ~0.3%/h with temperature through the evening, so calibrate
near the observation if absolute temperatures matter. A tracked spectrum gets
no live plot: its band power is meant to be flat, and an autoscaled trace of
it would only magnify noise into the appearance of structure.

Finished observations are plotted in kelvin when a gain calibration applies to
the tuning, and on an **LSR** velocity axis when the direction and epoch can be
worked out — H I is quoted in LSR everywhere, and the correction reaches
~30 km/s. Where the direction is unknown the axis stays topocentric and says so.
A solar track's recording is drawn as flux against UTC with the RSTN reference
in the subtitle, a drift scan as band power against time, and a pulsar
recording as its fold (profile at the predicted period, sub-integrations, the
stack of every night, PINT residuals).

Below the plot sit the recordings and the buttons that act on one:

- **Filter** — by category: spectra, drift scans, booked Sun, Sun monitor,
  pulsar, console. The default is everything but the Sun monitor; the choice is
  remembered in the browser. The newest 25 are listed, with *show all*; a live
  run is always listed.
- **Plot Result**, **Download file**, **View live recording** (re-plots the file
  being written every 30 s until the run ends).
- **Fit model** — the per-channel gain fit for a tracked spectrum, the
  total-power fit for a drift scan; not for a pulsar. *Apply as calibration*
  appears only for a fit that can be applied.
- **PRESTO fold** — pulsar recordings only: exports a `.fil` and folds it with
  prepfold at the topocentric period, as an independent check.
- **dB scale** — solar and drift plots only: 10 log10 of value over peak,
  floored at −30 dB, for sidelobes a percent of the peak.

Buttons that do not apply to the selected recording are greyed out.

#### Scheduler Tab
The main view for managing observations.

- **Add/Edit/Clone/Delete observations** with full parameter control
- **Automatic triggering** - observations start automatically at scheduled times
- **Late start recovery** - if the scheduler starts after a scheduled time, observations still within their window are started with remaining duration
- **Preemption** - if a new observation is due while another is running, the current one is stopped and the new one starts
- **Clash prevention** - overlapping observations cannot be saved; end times are calculated from start time + duration
- **Real-time status** - see running observation with countdown timer
- **Running item protection** - running observations cannot be edited, deleted, or disabled
- **Local and UTC time display** - schedule in local time, see both clocks
- **Auto-save** - changes are saved automatically
- **Manual start** - click play button to start any observation immediately
- **Receiver start/status** - manually start the B200 receiver for warm-up/testing and see whether the active receiver process is manual or observation-owned
- **Clone** - duplicate an observation's settings into a new item
- **Clear Past** - remove observations whose end time has passed
- **Import/Export** - save and load schedules as JSON
- **Audio notifications** - rising/falling tones when observations start/stop

#### Configuration Tab
Persistent settings saved to `scheduler_config.json`:

| Setting | Description |
|---|---|
| Banner Name / Subtitle | Customise the page title and heading; a blank subtitle shows the beam and T_sys in force. *Help tips* (hover explanations) is per browser, not saved here |
| Controller URL | SRT telescope controller address, normally `http://192.168.50.120` (empty to disable) |
| Slew Timeout | Max seconds to wait for telescope to reach target (default: 300) |
| Position Tolerance | Degrees within which the telescope is considered on-target (default: 0.5) |
| Observer Latitude | Observer latitude in degrees (+N), synced from controller on startup |
| Observer Longitude | Observer longitude in degrees (+E), synced from controller on startup |
| Observer Elevation | Observer elevation in metres |
| Min Elevation | Minimum elevation for satellite pass filtering (default: 10°) |
| Safety Camera | Video device and capture resolution |
| Receiver Python Executable | Path to radioconda Python used for the scheduler-managed receiver |
| SDR | The radio an Observe-tab run uses (a schedule entry names its own) |
| Instrument | The fixed instrument — LO, sample rate, gain, H I band edges, H I and continuum channel counts — and the pilot (on/off, burst interval, duty cap, burst amplitude, TX gain). Empty means the default in `tuning.py` / `pilot.py`; the pilot is off by default. A warning above the boxes: a change leaves every later recording uncalibrated until the bandpass and gain are re-measured |
| Data Output Folder | Where observation HDF5 files are saved |
| Log Lines to Display | Number of log lines shown in the Log tab |
| Sun monitor | `sun_monitor`: track the Sun with 3 s records whenever nothing holds the hardware, no booking is near and the Sun clears the measured horizon (off by default) |
| Pulsar monitor | `pulsar_monitor`: record B0329+54 in pulsar mode daily, ahead of the Sun monitor (off by default). `pulsar_monitor_window` is `follow` (open when the pulsar comes out from behind the measured horizon; the default) or `clock` (open at `pulsar_monitor_start`, default 20:00 local); `pulsar_monitor_hours` is the window length (default 16) |
| Sound on Start/Stop | Enable/disable audio notifications |

Both monitors rank below bookings and hand starts, the pulsar monitor above
the Sun monitor (no Sun run is started into the pulsar window, and one still
going when the window opens is stopped). Bookings win: a run ends short of the
next one, and the pulsar monitor resumes afterwards if 30 min of its window are
left; the pieces of one window share a `pulsar_session` and are timed as one
TOA. Anything started by hand, or *Stop*, stops a monitor run and holds both
monitors off for 30 min. A goto from the controller's own page is not seen by
the scheduler. `/api/status` reports both.

Some settings are not on the tab and are set in `scheduler_config.json` (every
key must be one of `_DEFAULT_CONFIG`'s), among them
`srt_controller_fallback_urls` (mDNS and the WiFi AP, tried after the primary
URL), `thunderbolt_device` / `thunderbolt_baud`, and
the **pulsar band** — `pulsar_sample_rate_hz` (default 32 Msps) and
`pulsar_lo_hz` (default 1413 MHz), passed to the receiver as `H1_PULSAR_RATE` /
`H1_PULSAR_LO`. Pulsar mode needs no H I line and is not held to the fixed
instrument.

If the scheduler is launched under a different Python, it re-execs itself under the configured receiver Python when that interpreter exists. This keeps scheduled observations, manual receiver starts, Sun scans, and SDR imports on the same radioconda environment. A manually started receiver is stopped before a scheduled observation starts so the SDR is not shared by two processes.

Configuration changes take effect immediately without restarting.

#### Log Tab
Displays the last N lines of `scheduler.log` with auto-refresh (5 second interval, toggleable). The log file uses rotating storage (5 MB max, 3 backups).

### Observation Parameters

| Parameter | Description |
|---|---|
| Name | Descriptive name for the observation |
| Start Date/Time | When to start (local time, leave date empty for "today") |
| Duration | How long to observe (minutes); end time is calculated automatically |
| Coordinates | Target position — see Coordinate Systems below |
| Comment | Free text, stored as the recording's `comment` attribute |
| Instrument | **Shown, not set** — the fixed instrument (see below) |
| Integration Time | Seconds per record (does not apply to a pulsar entry) |
| SDR Type | B200, RTL-SDR, or Demo |
| Respect local horizon | Advisory check against the measured horizon; trims a scheduled entry |
| Home the mount first | Run the physical homing before pointing, recording the counters at the stops and any count drift |
| Pilot off for this entry | Leave the pilot transmitter off for this run (the pilot is off by default in any case) |
| When Done | Action after observation ends: Stay, Go Home (Alt 0°, Az 0°), or Stow (Alt 90°, Az 180°) |
| Filename | Output file (auto-generated if empty) |

**The tuning is not an observation parameter.** Since issue #27 the B200 records
with a **fixed instrument** — LO 1418.905752 MHz, 8 Msps, gain 20 dB — set once
in `tuning.py`, overridable only on the Configuration tab (with a warning). The
centre-frequency, bandwidth, gain and channels boxes are gone from the form.
Every recording carries **two products**: an H I sub-band (1419.006–1422.306 MHz,
845 channels of 3.91 kHz) under the usual dataset names, and a continuum product
(the whole 8 MHz, 1024 channels) beside it. Continuum measurements always exclude
the H I band.

### Coordinate Systems

The form's *Observation* dropdown groups them by what the dish does:

| System | Description | Tracking |
|---|---|---|
| RA/Dec (Equatorial J2000) | Right Ascension / Declination | Tracks as Earth rotates |
| Galactic (l, b) | Galactic longitude / latitude | Tracks as Earth rotates |
| Famous targets | The simulator's target list (galactic fields, M31, M33, HVCs, Lockman Hole, Cas A, Cyg A, Tau A, Sun, Moon), in track or drift mode. Saved as an ordinary galactic, drift or object entry | As saved |
| Sun or Moon (`object`) | Select Sun or Moon by name | Automatic ephemeris tracking |
| Satellite (TLE) | Two-Line Element set | SGP4 propagation at 1 Hz |
| Fixed alt/az (`altaz`) | Direct altitude/azimuth pointing — a drift scan | Fixed position |
| Drift Scan | RA/Dec, Galactic or Sun/Moon source + beam-crossing time | Fixed position |
| PSR B0329+54 (`pulsar`) | The one pulsar this dish can fold; records the pulsar band, not spectra. Plan on 6 h or more, homing first | Tracks the catalogue J2000 position |
| Calibration day (`calibration`) | Repeated Sun rasters from sunrise to sunset (grid, spacing, interval; optionally archive old scans and clear the controller's model first) | Per raster |
| Horizon scan (`horizon`) | The radiometric horizon strip scan (azimuth and altitude steps, azimuth range); about two hours, for a dark dry night | Per strip |

The ESP32 controller treats sky targets below 10° altitude as below the local observing horizon. The Galactic Plane shortcut uses a separate, higher acquisition floor (45° by default): it picks the point on the plane nearest the galactic centre that is currently that high, then follows it down to the 10° horizon.

### Drift Scans

A drift scan parks the dish at a fixed alt/az and lets Earth's rotation carry the source through the beam. Select "Drift Scan" in the coordinate system dropdown and enter:

1. The source, in RA/Dec (J2000), Galactic (l, b), or a solar-system object (Sun or Moon)
2. The **beam-crossing time T** (local) — when the source should be at beam centre
3. A **symmetric window ±W minutes** — recording runs from T−W to T+W

The start time and duration are derived automatically (start = T−W, duration = 2W). At start time the scheduler computes the source's track around T, parks on the drive-grid point (0.5° encoder steps) the track passes closest to (`drift_park.py`, which reproduces the controller's pointing transform), sends that point to `/direct`, and starts the receiver with tracking off. The crossing time and the cross-drift miss are then known exactly and recorded. With `/pointing` unreadable it falls back to the source's alt/az at T and says so. The form previews the computed pointing live and warns if the source is below the horizon or in the azimuth dead zone (355–360°) at T; "Use Next Transit" fills T with the source's next meridian transit, the classical drift-scan geometry.

Because the pointing is recomputed for each day's beam-crossing time, an entry that repeats daily stays centred on the source with no sidereal bookkeeping. On a late start the geometry is preserved (T comes from the scheduled slot, not the actual start); only the front of the window is lost, along with the initial slew time as usual. The computed pointing, beam time, frame, and window are recorded in the HDF5 observation metadata (`drift_alt`, `drift_az`, `drift_beam_time`, `drift_frame`, `drift_window_min`).

### Satellite Tracking

The scheduler supports satellite tracking using Two-Line Element (TLE) sets:

1. Select "Satellite (TLE)" in the coordinate system dropdown
2. Enter a TLE by one of three methods:
   - **Search CelesTrak**: Type a satellite name or NORAD catalogue number and click "Fetch TLE"
   - **Paste**: Paste 2 or 3 TLE lines directly into the text area
   - **Load file**: Load a `.tle` or `.txt` file
3. Click "Compute Next Pass" to find the next pass above the minimum elevation
4. The start time, duration, and satellite name are auto-filled

During a satellite observation, a background thread uses PyEphem to propagate the TLE and sends `/direct?alt=X&az=Y` to the controller every second. When the satellite is below the horizon, no command is sent.

Observer location (latitude, longitude, elevation) and minimum pass elevation are set in the Configuration tab.

### Telescope Integration

When an SRT controller is configured, the scheduler:
1. Runs the physical homing first, if the entry asks for it, recording the counters at the stops
2. Sends the pointing/tracking command to the telescope
3. Waits for slewing to complete (polls `is_slewing` status)
4. For satellite observations, starts a background thread sending position updates at 1 Hz
5. Starts the SDR receiver
6. On completion: stops satellite tracking, sends home/stow command (if configured); a pulsar run is handed to `pulsar_toa.py` for its TOAs

There is no calibrator step: the old noise diode is gone (issue #39), and the
receiver's in-band reference is now the pilot (`pilot.py`, off by default).

The Configuration tab also exposes firmware update settings. The controller UI's **Update firmware** button asks the local scheduler to run PlatformIO in the configured environment (`wt32-eth01-ota` by default), which uploads to the controller over Ethernet OTA.

### Logging

All scheduler activity is logged to both the console (INFO level) and `scheduler.log` (DEBUG level):
- Observation start/stop events
- Telescope commands and slew status
- Preemption events
- Schedule loading and clash detection
- Errors with full tracebacks
- Firmware update progress from PlatformIO OTA

### Sun Scan Calibration

The Sun Scan tab runs `sun_scan.py` as a scheduler-owned pointing calibration workflow. It uses the configured observer location, controller URL, receiver backend, and cancellation state.

- Each measurement recomputes the Sun position immediately before slewing. Hardware scans recheck it after each slew and refine the command when motion took long enough for the Sun to move.
- Before a hardware scan, the scheduler resolves the live controller using the configured primary and fallback URLs. Every slew must be accepted and finish within the configured position tolerance; a controller error, telescope fault, stationary mount, wrong final position, or timeout stops immediately and is shown on the website with current and target coordinates.
- Calibration Day runs the Due's physical `HOME` sequence before every hardware raster, rather than trusting an ordinary commanded `Alt=0, Az=0` position. This re-establishes the mount reference at its physical limits. A rejected raster is re-homed and retried once before it counts as a failed scan.
- A B200 raster holds one SDR session for all points, explicitly selects `RX2`, and discards a short receiver warm-up capture. Starting the standalone receiver is blocked while Sun Scan or Calibration Day owns the B200.
- The website point counter advances only after the telescope has reached the requested grid point and a power measurement has completed; failed movement is never counted as scan data.
- Azimuth grid offsets are cross-elevation sky offsets; mount azimuth commands are expanded by `cos(altitude)`. A grid point outside the safe mount range stops the scan with a website error instead of recording a clipped, inaccurate point.
- Results include both `az_error_deg` (mount azimuth correction) and `az_error_sky_deg` (fitted sky/cross-elevation correction), plus mid-scan Sun position and scan start/end timestamps.
- Gaussian peaks must lie inside the measured grid and pass beam-width, uncertainty, and goodness-of-fit checks before a scan can enter calibration-day data.
- Cancelling a scan stops before fitting partial data.

Calibration Day repeatedly performs a complete N×N Sun scan on a start-to-start interval, saves each successful fit, and continues until sunset, cancellation, or three consecutive failures. The pointing model fits four terms — IE and IA (elevation and azimuth index), AN and AE (the two tilts) — plus CA (collimation) when the scans span enough altitude and AZSCALE when they span 90° of azimuth; any term can be held at a stored value, which is how a feed change is refitted (IE and CA only). It needs at least four scans; applying it needs 30° of Sun azimuth coverage, a condition number under 10⁴ and significant tilt terms. It uses only successful finite scans, weights them by their fit uncertainties, leaves out scans from behind the measured horizon, and reports parameter uncertainty, RMS residuals, coverage, and matrix conditioning in the web interface. A large difference between the displayed and physical mount position indicates lost encoder reference, mechanical slip, or a drive/power fault; run physical homing and correct the hardware problem rather than accepting a poor fit. **Apply to Telescope** POSTs the fitted terms as a document to the controller's `/pointing/apply` (`sun_scan.pointing_model_document`), which keeps it in its own NVS namespace; the observer position stays the true site and the operator's offset boxes are not touched. A controller rejection is reported.

## Configuration

Default parameters can be modified at the top of `b210_h1_receiver.py`:

```python
CENTER_FREQ = 1420.405e6    # Hydrogen line frequency (Hz)
FFT_SIZE = 4096             # FFT bins (frequency resolution)
INTEGRATION_TIME = 3.0      # Seconds between HDF5 saves
```

### Where recordings go, and what they are called

Every recording lands in `data/observations/`, named for when it was made and
what the mount was doing:

```
20260825_192937_drift.h5        the dish was parked; the sky drifted through the beam
20260825_201455_track.h5        the mount followed the source
20260825_143012_manual.h5       started at the console, nobody commanded the mount
20260926_203116_pulsar.h5       a pulsar entry: the fast total-power record, not spectra
```

and nothing else. The target name, the coordinates, the
tuning and the calibration in force are all attributes *inside* the file, so
repeating any of them in the name would only make a second copy free to
disagree with the first after a rename or an edit to the schedule entry.

`track` and `drift` describe the mount, not the box the entry was typed into:
an `altaz` entry is a **drift** scan, because the scheduler sends it to
`/direct` and leaves tracking off. The same word is stored as the
`observation_mode` attribute, so a renamed file still says what it was.

The convention lives in `observation_files.py`, shared by the scheduler and the
receiver. `H1_OUTPUT_FILE` still overrides it outright.

The scheduler passes the fixed instrument and the run's settings through the
environment:
- `H1_INSTRUMENT` — the fixed-instrument document (JSON); the receiver ignores
  `--sample-rate` and `--gain` in headless mode so a stale launcher cannot retune
  a scheduled run
- `H1_INTEGRATION_TIME`
- `H1_OUTPUT_FILE`
- `H1_OBS_METADATA` — the observation metadata above
- `H1_MODE=pulsar`, with `H1_PULSAR_RATE` / `H1_PULSAR_LO` from the pulsar
  band settings, for a pulsar entry

### Frequency Resolution

The frequency resolution is determined by:

```
Resolution = Sample Rate / FFT Size
```

| Sample Rate | FFT Size | Resolution |
|---|---|---|
| 2.048 MHz | 4096 | 500 Hz |
| 2.4 MHz | 4096 | 586 Hz |
| 5.0 MHz | 4096 | 1.22 kHz |
| 2.4 MHz | 8192 | 293 Hz |

For hydrogen line observations, ~500 Hz resolution is typically sufficient.

## Output Data Format

Data is saved to an HDF5 file with the following structure:

A recording carries **two products** (issue #27) and can be **read while it is
being written** (HDF5 SWMR): open it read-only, or in h5py with
`h5py.File(path, 'r', swmr=True)`. A change of spectral geometry — which can now
only happen on the console window, not a scheduled run — rolls to a new
timestamped file.

### Datasets

| Dataset | Shape | Type | Description |
|---|---|---|---|
| `frequency_hz` | (N_ch,) | float64 | H I sub-band axis in Hz (845 channels) |
| `spectra_kelvin` **or** `spectra_linear` | (N_rec, N_ch) | float32 | H I product; kelvin when calibrated, else counts |
| `frequency_hz_wide` | (N_wide,) | float64 | Continuum product axis (1024 channels over 8 MHz) |
| `spectra_wide_kelvin` **or** `spectra_wide_linear` | (N_rec, N_wide) | float32 | Continuum product |
| `bandpass_correction`, `bandpass_valid` (and `_wide`) | (N,) | float32 / bool | Per-channel correction applied at write time, and where the template speaks |
| `timestamps` | (N_rec,) | float64 | Unix time at the centre of each record (since 2026-08-27; the end before that) |
| `integration_times` | (N_rec,) | float32 | Actual integration per record |
| `overflows`, `underflows` | (N_rec,) | int32 | UHD overflows, and pilot TX underflows, during the record |

**The units are in the dataset name.** `spectra_kelvin` means the bandpass template
and gain in force applied to this tuning; `spectra_linear` means they did not and
the data are raw counts. Asking for the wrong one raises `KeyError`. Writing kelvin
is exactly reversible — the correction, gain and T_sys travel in the file — and
`observation_plot.read_observation` reverses it so the fitting code always gets counts.

### Attributes

| Attribute | Description |
|---|---|
| `sdr_type` | SDR used ('b210', 'rtlsdr', or 'demo') |
| `center_freq_hz`, `sample_rate_hz`, `gain_db` | The fixed instrument's LO, rate and gain |
| `instrument` | The whole fixed-instrument document (JSON) |
| `h1_band_hz`, `continuum_band_hz` | The two bands, `[low, high]` in Hz |
| `spectra_units`, `spectra_wide_units` | `K` or `counts`, per product |
| `applied_gain_counts_per_k`, `applied_t_sys_k` | The calibration applied when in kelvin |
| `bandpass_template`, `bandpass_template_wide`, `gain_calibration` | The calibration in force, as JSON, so a file is reducible off-machine |
| `beam_fwhm_deg`, `effective_area_m2`, `site_lat_deg/lon_deg/height_m` | Measured beam and surveyed site |
| `clock_source`, `clock_ref_locked` | Which 10 MHz the radio ran from, and whether it reported lock |
| `nominal_integration_time`, `created` | Target integration; ISO 8601 creation time |

When launched from the scheduler, additional observation metadata is included:

| Attribute | Description |
|---|---|
| `obs_name`, `comment` | Name, and the free text from the schedule form |
| `observation_mode` | `track`, `drift`, `pulsar` or `manual` — the word in the filename |
| `coord_system` | altaz, radec, galactic, object, drift, satellite, pulsar |
| `object_name` | Solar system object (sun, moon, jupiter) if applicable |
| `coord1_deg/min/sec`, `coord2_deg/min/sec` | Target coordinates |
| `sun_monitor`, `pulsar_monitor`, `pulsar_session` | Whether a monitor started the run, and the pulsar window it belongs to |
| `pointing_terms` | The pointing model in force (JSON), for reconstructing the commanded drive position |
| `reference_*` | The Thunderbolt's state at the start (`reference_state` `absent` when none is read) |
| `duration_minutes`, `start_date`, `start_time` | The scheduled slot |
| `drift_frame`, `drift_window_min`, `drift_beam_time` | Drift scans: frame, half-window W, planned crossing T |
| `drift_alt` / `drift_az` | The true alt/az commanded |
| `drift_drive_alt` / `drift_drive_az` | The drive-grid point parked on |
| `drift_crossing_time`, `drift_crossing_offset_deg` | When the source crosses the parked beam, and how far off centre |
| `homed_first`, `homing_count_error_alt_deg`, `homing_count_error_az_deg`, `homing_drift_alt_deg`, `homing_drift_az_deg` | Homing before the run: the raw first-approach counters (a fixed switch-detection offset, normally alt −1.0 / az −0.5, plus any drift; the name is historical) and the drift alone (0 when inside the normal range) |

### Pulsar recordings

A pulsar entry (`H1_MODE=pulsar`) records no spectra: the band power summed per
millisecond, by default one channel over 32 MHz at 1413 MHz (~14 MB an hour),
SWMR from creation. `H1_PULSAR_NCHAN=16` gives a 16-channel filterbank instead.

| Dataset | Shape | Description |
|---|---|---|
| `power` | (N, nchan) float32 | Band power per row, `dt_s` apart from `t0_unix` |
| `frequency_hz` | (nchan,) | Channel centres |
| `time_marks` | (M, 2) float64 | (row, radio time) at the first sample and after every overflow, from the `rx_time` tags; rows are fractional (`time_marks_exact = 1`) |
| `overflow_marks`, `underflow_marks` | (K, 2) int64 | (row, count) for each batch of overflows or TX underflows |

Attributes beside the usual radio, instrument, site and scheduler metadata:
`mode` = `pulsar`, `dt_s`, `nchan`, `channel_width_hz`, `t0_unix`,
`created_utc`; the catalogue numbers (`pulsar_name`, `pulsar_period_s`,
`pulsar_pdot`, `pulsar_pepoch_mjd`, `pulsar_dm`, ...); the time source
(`time_source` `pps` or `host`, `time_pps_verified`,
`time_device_minus_host_s`, `time_last_pps`); and the calibration in force at
the start (`cal_t_sys_k`, `cal_effective_area_m2`, `cal_t_sys_utc`,
`cal_beam_utc`, from 2026-09-30), so the fold's mK and mJy scales stay the
recording's own. The fold, the TOAs and the PRESTO export are in
`pulsar_fold.py`, `pulsar_toa.py` and `sigproc_export.py`; see
`../docs/PULSAR_PROCESSING.tex`.

### Reading Data in Python

Recordings are written in HDF5's single-writer / multiple-reader mode, so a
file **can be opened for reading while the receiver is still writing it** —
from the Observe tab's *View live recording*, or in h5py with
`h5py.File(path, 'r', swmr=True)` (a plain open still hits the lock while the
run is in progress; that is the protection, and the keyword is how a reader
says it knows the file is live). The on-disk format is HDF5 1.10
(`libver='latest'`); h5py, current MATLAB and the notebook read it.

A recording holds its spectra under **one of two names**, and the name is the
units. `spectra_kelvin` means the bandpass and gain in force were applied at
write time and the numbers are antenna temperature in K; `spectra_linear` means
no calibration applied to that tuning and the numbers are raw counts. Ask for
the wrong one and you get a `KeyError` — which is the point, and is why the
units are not merely an attribute you could forget to read.

```python
import h5py
import numpy as np
import matplotlib.pyplot as plt

with h5py.File('data/observations/20260825_192937_drift.h5', 'r') as hf:
    freq_mhz = hf['frequency_hz'][:] / 1e6
    timestamps = hf['timestamps'][:]

    # The dataset name is the units. Never guess.
    calibrated = 'spectra_kelvin' in hf
    spectra = hf['spectra_kelvin' if calibrated else 'spectra_linear'][:]
    units = 'K' if calibrated else 'counts'

    print(f"SDR: {hf.attrs['sdr_type']}")
    print(f"Mode: {hf.attrs.get('observation_mode', '?')}"
          f"  target: {hf.attrs.get('obs_name', '?')}")
    print(f"Center freq: {hf.attrs['center_freq_hz']/1e6:.3f} MHz")
    print(f"Sample rate: {hf.attrs['sample_rate_hz']/1e6:.3f} MHz")
    print(f"{len(timestamps)} spectra in {units}")

    # To go back to raw counts (the calibration travels with the file):
    if calibrated:
        raw = ((spectra + hf.attrs['applied_t_sys_k'])
               * hf.attrs['applied_gain_counts_per_k']
               * hf['bandpass_correction'][:])

plt.figure(figsize=(12, 6))
plt.plot(freq_mhz, np.mean(spectra, axis=0))
plt.axvline(x=1420.405, color='r', linestyle='--', label='H I line')
plt.xlabel('Frequency (MHz)')
plt.ylabel(f'Antenna temperature ({units})')
plt.legend(); plt.grid(True); plt.show()

plt.figure(figsize=(12, 8))
plt.imshow(spectra, aspect='auto',
           extent=[freq_mhz[0], freq_mhz[-1], len(spectra), 0], cmap='viridis')
plt.colorbar(label=f'Antenna temperature ({units})')
plt.xlabel('Frequency (MHz)'); plt.ylabel('Time (integration #)')
plt.show()
```

Uncalibrated counts still want `10*np.log10(...)` for display; kelvin does not —
a temperature is already linear in the thing you care about, and taking its
logarithm throws away the calibration you just gained.

See `../notebooks/read_h1_data.ipynb` for a more complete example with metadata display and zoomed H I views, and `../notebooks/solar_flux_scallop.ipynb` for a solar track reduced end to end.

## Troubleshooting

### SDR Not Found

**B200/B210:**
```bash
# Check if device is detected
uhd_find_devices
```
If not found:
- Ensure USB 3.0 connection (B200 and B210 require USB 3.0)
- Install/reinstall UHD drivers
- On Windows, check Device Manager for driver issues

**RTL-SDR:**
```bash
# Check if device is detected
rtl_test
```
If not found:
- On Windows, use Zadig to install WinUSB driver
- Ensure no other application is using the device

**Demo Mode:**
If no SDR is available, the receiver automatically falls back to demo mode with simulated data.

### Import Errors

If you get `ModuleNotFoundError`:
```bash
# Ensure Radioconda is activated
conda activate radioconda

# Verify packages are installed
python -c "from gnuradio import gr; print('GNU Radio OK')"
python -c "import osmosdr; print('osmosdr OK')"
```

### Scheduler Not Starting Observations

- Ensure you run the scheduler from the radioconda environment
- Check that observations are enabled (checkbox checked)
- Verify the scheduled time is in local time
- Watch the console output for status messages

### Overflow Errors

If you see "O" printed or overflow warnings:
- Reduce sample rate
- Close other CPU-intensive applications
- On laptops, ensure power is plugged in (performance mode)

### Poor Signal / No Hydrogen Line Visible

- Verify antenna is connected and pointed at a hydrogen-rich region (Milky Way)
- Increase gain
- Use an LNA at the antenna
- Increase integration time for more averaging
- Check for local RFI interference

### Qt/GUI Issues

If the GUI doesn't appear or crashes:
```bash
# Try setting Qt platform explicitly
export QT_QPA_PLATFORM=xcb  # Linux
set QT_QPA_PLATFORM=windows  # Windows
```

## Observation Tips

### Best Targets

The hydrogen line is strongest when observing:
- The galactic plane (Milky Way)
- Specific coordinates with known HI emissions

### Doppler Shift

The hydrogen line can be Doppler-shifted due to:
- Galactic rotation
- Motion of hydrogen clouds
- Earth's motion

The rest frequency is 1420.405751 MHz. Observed shifts indicate radial velocity:
```
v = c * (f_rest - f_observed) / f_rest
```

### Integration Time

Longer integration times improve signal-to-noise ratio:
- SNR improvement = sqrt(integration_time)
- 1 minute integration: ~8x SNR improvement over 1 second
- 1 hour integration: ~60x SNR improvement over 1 second

## License

This project is provided as-is for educational and amateur radio astronomy purposes.

## References

- [NRAO Introduction to Radio Astronomy](https://www.cv.nrao.edu/~sransom/web/xxx.html)
- [GNU Radio Wiki](https://wiki.gnuradio.org/)
- [Ettus Research UHD Documentation](https://files.ettus.com/manual/)
- [RTL-SDR Blog](https://www.rtl-sdr.com/)

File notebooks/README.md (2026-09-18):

# Worked data reductions

Notebooks that take a recording apart by hand. Each one does what the pipeline
does, step by step, so the assumptions at each stage are visible instead of
buried in one call — and each ends by showing the one-line equivalent.

They are for reading and for learning the instrument, not for doing the
observatory's work. `observation_plot.plot_observation` is what you want for
that.

| notebook | what it does |
|---|---|
| `read_h1_data.ipynb` | Opens a recording, prints what is in it, and plots it — a tracked spectrum as a spectrum, a drift scan as its band-power curve. The place to start. |
| `solar_flux_scallop.ipynb` | A solar track end to end: continuum window, band mean, the tracking scallop fitted and removed, the antenna theorem, the atmosphere, and the comparison against the RSTN reference network. |
| `solar_flux_rstn.ipynb` | The Sun at 1415 MHz over one UTC day: the RSTN network's one-second archive from NOAA beside our own solar tracks, raw or binned onto common UTC edges, with a test of whether the two move together. RSTN runs about a month behind, and the last cell says which of our days can be compared yet. Downloads are cached in `~/.cache/srt_rstn/`. |

## Running them

They find the repository from their own location, so they run from here, from
the repository root, or from a copy elsewhere with `SRT_ROOT` set:

```
cd notebooks && jupyter lab
SRT_ROOT=/path/to/21-cm-radio-telescope-v2 jupyter lab   # from anywhere else
```

Recordings are read from `receiver_scheduler/data/observations/`. Nothing here
writes to the observatory's data — any output lands beside the notebook.

Either interpreter works: the observatory's radioconda
(`/home/astro/radioconda/bin/python`) or the project venv (`.venv`). Both were
checked against the same recording and give the same numbers.

`read_h1_data.ipynb` needs only `h5py`, `numpy` and `matplotlib`.
`solar_flux_scallop.ipynb` also imports `scallop.py` and `observation_plot.py`
from `receiver_scheduler/` — and `ephem`, `scipy` and `astropy` through them —
because reconstructing where the mount was *commanded* to point means
reproducing the firmware's own transform, and a hand copy in a notebook would
drift away from the firmware silently.

For a fresh venv, `receiver_scheduler/requirements.txt` covers all of it.
`solar_flux_rstn.ipynb` draws **interactive** figures — drag to zoom, pan,
the house to go back — when the kernel has `ipympl`, which the project `.venv`
does. In a kernel without it the figures come out static and the first cell
says so; set `INTERACTIVE = False` there for static figures anyway.
Install one package at a time on the observatory host; resolving the whole list
in one pip run was killed by the OOM killer there.

## Outputs are not committed

Git stores every notebook stripped of its outputs and execution counts
(`.gitattributes` names the `nbstripout` filter), so run them as freely as you
like: your working copy keeps its figures, the repository never sees them, and
a notebook you have only run shows as unchanged. The filter is registered per
clone, once — it is already done on the observatory host:

```
.venv/bin/python -m pip install nbstripout
.venv/bin/python -m nbstripout --install
```

Without that, a clone commits notebooks as they are, outputs and all.

## A recording still being written

Both open a live file read-only and show what has arrived so far, so you can
watch an observation reduce while it runs. `docs/CALIBRATION.md` is the
reference for what every correction means and the order they are applied in.

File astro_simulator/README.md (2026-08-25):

# Astro simulator

Simulate what a small radio telescope (default: a 3-m dish) observes when
pointed at the 21-cm sky, using the [HI4PI survey](https://ui.adsabs.harvard.edu/abs/2016A%26A...594A.116H)
(HI4PI Collaboration 2016, A&A 594, A116) as the "true" sky. HI4PI has a
16.2′ beam and 1.29 km/s channels — far finer than a small dish's ~5°
beam — so the simulated antenna-temperature spectrum is the beam-weighted
average of the survey brightness temperature, with optional continuum
sources, radiometer noise and velocity-frame conversion.

## Quick start

```
pip install -r requirements.txt
python astro_simulator.py
```

Or use the launchers: `run.bat` (Windows) / `./run.sh` (Linux; make it
executable once with `chmod +x run.sh`). Both pass extra arguments
through to `astro_simulator.py`.

The repo ships `hi4pi_compact.npz.xz` (~23 MB), a pre-smoothed compact
version of the survey tuned to small-dish beams, so **no download is
needed** to start: a window opens with the all-sky N_HI map — **click
anywhere** to point the dish and get its spectrum. The full ~33 GiB
survey cube is only fetched from CDS if you ask for something the
compact data cannot honour (a beam below ~1.5°, a band beyond
±470 km/s) or run with `--full` (interrupted downloads resume).

## Scripts

| Script | Purpose |
|---|---|
| `astro_simulator.py` | Interactive GUI: click the all-sky map, get the dish spectrum. Editable pointing, beam, T_sys, integration time, bandwidth, band centre, spectrometer channel count (pre-filled with the band's native count at startup; emptying the box also means native resolution; the spectrum draws as channel steps) and velocity frame (LSR/SSB/topocentric); target list (H I targets plus the continuum sources Cyg A, Cas A, Tau A, the Sun and the Moon), a map toggle between the N_HI and 1420 MHz continuum skies, site horizon/visibility overlays, and a live RA/Dec + Alt/Az readout for the current pointing beside the map. The lower panel is modal: with the H I map it shows the spectrum; with the continuum map it shows a **drift scan** — band-averaged T_A (H I included when in-band) for the sky drifting through a beam parked on the current target, any target, above the horizon or not, centred on beam-centre transit over the duration set in the **scan (min)** box, with per-sample noise. A **Realise** button hands the simulation to the real telescope (ESP32 controller, `--controller` URL): with the H I map it starts galactic tracking of the pointing; with the continuum map it cancels tracking and parks the dish at the drift-scan start, so the target transits the beam centre half a scan later. Press `s` to save the current spectrum (PNG + txt). |
| `hi4pi_compress.py` | Regenerates `hi4pi_compact.npz.xz` from the full cube: block-averages to 0.5° pixels, smooths to 1° total resolution, trims to \|v\| ≤ 470 km/s, zeroes below 3σ, quantizes to int16 (0.01 K) and LZMA-compresses — 33 GiB → ~23 MB, exact to <0.5% for beams ≥ 1.6°. |
| `continuum_compress.py` | Regenerates `continuum_1420_compact.npz.xz` from the Stockert/Villa-Elisa 1420 MHz continuum survey (CADE HEALPix, fetched automatically, 3.2 MiB): same 0.5° grid and 1° resolution as the H I cube, zero level (CMB + isotropic, ~3.2 K) stored separately, strong sources (Cyg A, Cas A, Tau A — saturated/blanked in the survey) removed for analytic re-insertion. ~0.7 MB. |
| `hi4pi_data.py` | Data download helper (see below). Run directly to pre-fetch the all-sky files. |

Example:

```
python astro_simulator.py --bw 2 --tsys 100 --tint 60 --nchan 1024
```

## Browser version

[web/](web/) holds an install-free HTML/JavaScript port restricted to
the compact datasets — one static folder, ~36 MB of data bundles,
validated against this simulator to <1 mK by a golden-vector test
suite. See [web/README.md](web/README.md).

## The two sky datasets

The GUI can draw its spectra from either of two forms of the survey:

| | `hi4pi_compact.npz.xz` (in the repo) | `hi4pi_allsky_gal_CAR.fits` (CDS) |
|---|---|---|
| Size | ~23 MB | ~33 GiB |
| Resolution | pre-smoothed to 1.0°, 0.5° pixels | native 16.2′, 5′ pixels |
| Velocity range | \|v_LSR\| ≤ 470 km/s | \|v_LSR\| ≤ 607 km/s |
| Beams supported | ≥ ~1.5° (any dish ≲ 7 m) | ≥ 0.2° |
| Spectrum speed | ~10 ms (held in RAM) | 0.3–2.5 s (memory-mapped) |

The compact file is quantized to 0.01 K with everything below 3σ of its
8.7 mK noise floor zeroed. Because it stores its own resolution, the
simulator convolves only the *residual* beam, so the delivered beam is
exactly what you asked for; for the default 3-m dish (4.9° beam) the
two datasets agree to <0.2% of peak per channel — far below any
simulated radiometer noise, i.e. indistinguishable in use.

Selection is automatic: the compact file is used whenever it is present.
If you request something it cannot honour — a beam finer than ~1.5° or a
band centre beyond its velocity range — the GUI switches to the full
cube on the fly if that file is on disk, and otherwise clamps the
request and tells you (it never starts the 33 GiB download uninvited).
When the beam and band later return to values the compact data can
serve (say the beam goes from 0.2° back to 5°), it switches back just
as automatically — the compact cube stays cached in RAM, so the return
is immediate.

## Continuum sky

`continuum_1420_compact.npz.xz` (in the repo, ~0.7 MB) adds the diffuse
1420 MHz continuum from the Stockert/Villa-Elisa all-sky survey (Reich
1982; Reich & Reich 1986; Reich, Testori & Reich 2001) under the
analytic point sources. Every spectrum then rides on the real continuum
background — Cygnus X, the galactic ridge, the North Polar Spur — which
both shapes drift-scan baselines and feeds the noise estimate: the
radiometer rms uses T_sys + T_A(pointing), so pointing at the plane
degrades the SNR just as it does at the telescope. Drift-scan samples
carry a second noise term in quadrature — the measured common-mode
instability of band-integrated total power (`GAIN_INSTABILITY` in
`instrument.py`, 2.3×10⁻⁴ of T_sys per sample, receiver gain and
atmosphere together) — because at the huge Δν·τ of a band integral the
ideal radiometer floor is not what the receiver delivers; per-channel
spectra stay radiometer-only, where the same wobble is common mode,
below thermal, and removed by any baseline handling. Notes: the survey's
uniform zero level (CMB + isotropic, ~3.2 K) is subtracted and assumed
to live inside your T_sys; the survey saturates or blanks the strongest
compact sources, so Cyg A, Cas A and Tau A are removed from the map and
carried analytically at their true fluxes (the Sun and Moon, which no
static map can hold, are analytic too, at their launch-time positions);
the map's resolution floor is 1°, irrelevant for beams ≥ 1.5°. Delete or rename the file (or pass
`--continuum ""`) to fall back to point sources on an empty sky.
Force the full cube with `--full` (this *will* download it if missing);
point at a different compact file with `--compact PATH`.

## Data

The raw survey files are fetched automatically the first time a script
needs them (`hi4pi_data.py`; downloads resume if interrupted). The
HI4PI files come from CDS catalogue
[J/A+A/594/A116](https://cdsarc.cds.unistra.fr/ftp/J/A+A/594/A116/):

| Local file | Source | Size |
|---|---|---|
| `hi4pi_allsky_gal_CAR.fits` | `ALLSKY/GAL/CAR.fits` — all-sky galactic plate-carrée spectral cube | ~33 GiB |
| `hi4pi.fits` | `NHI_HPX.fits.gz` — N_HI HEALPix table (display map) | 318 MiB (~600 MiB unpacked) |
| `stockert_villaelisa_1420MHz_healpix.fits` | [LAMBDA mirror](https://lambda.gsfc.nasa.gov/product/foreground/fg_stockert_villa_info.html) of the CADE HEALPix Stockert/Villa-Elisa 1420 MHz continuum survey — only needed to regenerate the compact continuum map | 3.2 MiB |

`hi4pi_compact.npz.xz`, `continuum_1420_compact.npz.xz` and
`nhi_grid_cache.npy` (the gridded N_HI display map) are all committed
to the repo and derived from these files, so a fresh clone runs the GUI
with no downloads at all; regenerate them with `hi4pi_compress.py`,
`continuum_compress.py`, or (for the cache) by deleting the file before
a launch with `hi4pi.fits` present.

## Observer site

The horizon, visibility loops and topocentric velocity frame default to
Glasgow; change the defaults at the top of `astro_simulator.py` or per
run with `--site/--lat/--lon/--height`.

## Requirements

Python 3.9+, `numpy`, `matplotlib`, `astropy` (`pip install -r requirements.txt`).
The GUI needs an interactive matplotlib backend (TkAgg or QtAgg).

## Acknowledgement

HI4PI: a full-sky HI survey based on EBHIS and GASS, HI4PI Collaboration,
2016, A&A 594, A116. Data via CDS/VizieR, catalogue J/A+A/594/A116.

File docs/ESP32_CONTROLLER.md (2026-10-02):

# WT32-ETH01 Controller - Technical Manual

**Version 2.1 (Arduino/PlatformIO)**
**Acre Road Observatory, Glasgow**

---

## Table of Contents

1. [Overview](#1-overview)
2. [Installation](#2-installation)
3. [Configuration Reference](#3-configuration-reference)
4. [Source Code Structure](#4-source-code-structure)
5. [HTTP API](#5-http-api)
6. [Stellarium Protocol](#6-stellarium-protocol)
7. [Coordinate System](#7-coordinate-system)
8. [Time Synchronization](#8-time-synchronization)
9. [Networking](#9-networking)
10. [Development](#10-development)
11. [Troubleshooting](#11-troubleshooting)

---

## 1. Overview

The WT32-ETH01 controller provides the high-level interface for the SRT drive system:

- **Web interface** for manual control and monitoring
- **Stellarium integration** via TCP telescope protocol
- **Coordinate transforms** from RA/Dec (J2000) to true Alt/Az
- **Pointing model**: true Alt/Az to drive coordinates and back (`pointing.cpp`), stored in its own NVS namespace
- **Ephemeris calculations** for Sun and Moon (topocentric) positions
- **Time synchronization** via SNTP (hourly) or browser fallback
- **Runtime configurable settings** saved to flash (NVS)
- **Networking** via native Ethernet + WiFi (AP + station mode)
- **mDNS and Ethernet OTA** for `srt-controller.local` discovery and network firmware updates
- **Diagnostics** that survive a reset (`/diag`) and a 30 s loop watchdog
- **Ethernet address**: `http://192.168.50.120/` — a private point-to-point link
  to the observatory computer (`192.168.50.1`), which serves its DHCP lease and
  NATs it out for NTP. Not the observatory LAN.

### Architecture

```
+------------------+     +------------------+     +------------------+
|   Stellarium     |     |   Web Browser    |     |   NTP Server     |
|   (TCP:10001)    |     |   (HTTP:80)      |     |                  |
+--------+---------+     +--------+---------+     +--------+---------+
         |                        |                        |
         +------------------------+------------------------+
                                  |
                         +--------+---------+
                         |                  |
                         |   WT32-ETH01     |
                         |   (Arduino C++)  |
                         |                  |
                         |  main.cpp        |
                         |  coordinates.cpp |
                         |  pointing.cpp    |
                         |  web_server.cpp  |
                         |  stellarium.cpp  |
                         +--------+---------+
                                  |
                             UART Serial
                                  |
                         +--------+---------+
                         |   Arduino Due    |
                         +------------------+
```

### Source File Structure

| File | Purpose |
|---|---|
| `src/main.cpp` | Main application, tracking loop, time sync |
| `src/config.h` | Default configuration values |
| `src/settings.cpp/h` | Runtime settings with NVS persistence |
| `src/coordinates.cpp/h` | Astronomical coordinate transforms |
| `src/pointing.cpp/h` | Pointing model, refraction, `trueToDrive()` / `driveToTrue()`, mount-limit helpers |
| `src/web_server.cpp/h` | HTTP server and web interface |
| `src/stellarium.cpp/h` | Stellarium telescope protocol |
| `src/srt_serial.cpp/h` | Serial communication with Due, drive-target acknowledgement, homing report |
| `src/wifi_manager.cpp/h` | WiFi AP/station management |
| `src/diag.cpp/h` | RTC-memory record of the last boot, reset reason, loop watchdog |
| `src/sync.cpp/h` | Recursive mutex (`SRTLock`) shared by `loopTask` and `async_tcp` |
| `src/state.h` | Global state structure, clock-state helpers |
| `src/index_html.h` | Embedded web interface HTML |
| `test/test_coordinates`, `test/test_pointing` | Host unit tests (`native` environment) |
| `test/shim/` | Minimal `Arduino.h` / `Preferences.h` so `pointing.cpp` builds on the host |

---

## 2. Installation

### Prerequisites

- WT32-ETH01 module (ESP32 with built-in LAN8720 Ethernet)
- Temporary FT232 USB-TTL programmer for first flash or recovery
- [PlatformIO](https://platformio.org/) (VS Code extension or CLI)

### Build and Upload

`pio` is not on PATH. On the observatory Linux host it is
`~/.platformio/penv/bin/pio`; on Windows `~/.platformio/penv/Scripts/pio.exe`.

```bash
cd 21-cm-radio-telescope-v2/esp32_controller_arduino
PIO=~/.platformio/penv/bin/pio

# Build for WT32-ETH01 (the default environment)
$PIO run -e wt32-eth01

# First serial flash or recovery (temporary FT232 on TX0/RX0)
$PIO run -e wt32-eth01 --target upload

# Routine Ethernet OTA update after first flash
$PIO run -e wt32-eth01-ota --target upload

# Host unit tests: test/test_coordinates and test/test_pointing, no board
$PIO test -e native

# Monitor serial output (needs the FT232 on TX0/RX0; the WT32 has no USB)
$PIO device monitor
```

`esp32s3` is a legacy environment for a board no longer used. `wt32-eth01`
is the canonical target and must always build clean.

### Verify Installation

After upload, the serial monitor should show (abridged):

```
SRT Controller starting...
Settings loaded from NVS
Due serial initialized
Initializing Ethernet...
  Mode: DHCP
ETH IP: 192.168.50.120, Speed: 100Mbps, Full Duplex
Ethernet connected (DNS 192.168.50.1) - syncing time
SNTP started (pool.ntp.org), resync every 3600 s
AP started: SRT_Controller at 192.168.4.1
...
Async web server listening on port 80
Stellarium async server listening on port 10001
Free memory: <n> bytes
Ethernet IP: 192.168.50.120
AP IP: 192.168.4.1
```

The repository OTA target is configured for `192.168.50.120:3232`.

---

## 3. Configuration Reference

### Compile-Time Defaults (config.h)

These values are used as defaults when no saved settings exist:

```cpp
// WiFi Access Point
#define WIFI_AP_SSID "SRT_Controller"
#define WIFI_AP_PASSWORD "radio1420"

// Serial connection to Arduino Due (WT32-ETH01 pins)
#define DUE_UART_TX 4    // WT32 IO4 -> Due RX (pin 19)
#define DUE_UART_RX 14   // WT32 IO14 <- Due TX (pin 18)
#define DUE_BAUD_RATE 115200

// Observer location (Acre Road Observatory, Glasgow)
#define OBSERVER_LAT 55.902426
#define OBSERVER_LON -4.307865

// NTP: name first, numeric fallback (time.cloudflare.com) if DNS fails
#define NTP_SERVER "pool.ntp.org"
#define NTP_SERVER_FALLBACK "162.159.200.123"
#define NTP_SYNC_INTERVAL_MS 3600000UL  // SNTP resync every hour
#define CLOCK_STALE_WARN_S   18000UL    // warn after 5 h with no sync
#define NTP_RETRY_INTERVAL_MS 300000UL  // restart SNTP every 5 min until first sync

// Ethernet static-IP fallback (only if DHCP is switched off)
#define DEFAULT_ETH_STATIC_IP "192.168.50.120"
#define DEFAULT_ETH_GATEWAY   "192.168.50.1"
#define DEFAULT_ETH_SUBNET    "255.255.255.0"
#define DEFAULT_ETH_DNS       "192.168.50.1"

// Mount software limits (degrees, DRIVE frame)
#define MOUNT_AZ_MIN 2.0
#define MOUNT_AZ_MAX 353.0
#define MOUNT_ALT_MIN 0.0
#define MOUNT_ALT_MAX 90.0

// Observing horizon (degrees, TRUE frame)
#define TRACKING_HORIZON_ALT 10.0

// Acquisition floor for the galactic-plane target (degrees)
#define GALACTIC_PLANE_MIN_ALT 45.0

// Stow position (degrees, DRIVE frame; pointing model bypassed)
#define STOW_ALT 90.0
#define STOW_AZ 180.0

// Position deadband (degrees)
#define POSITION_DEADBAND 0.25
```

### Runtime Settings (Web Interface)

Settings can be changed via the web interface Settings tab:

| Setting | Description | Default |
|---|---|---|
| Observer Lat/Lon | True site position (never a pointing correction) | 55.902426, -4.307865 |
| Software Limits | Mount limits in the drive frame, applied after the pointing model | 2-353, 0-90 |
| Observing Horizon | Minimum true altitude for sky targets; below it, tracking parks the dish | 10 deg |
| Galactic plane acquire above | Lowest altitude at which the galactic-plane target may be *started* | 45 deg |
| Stow Position | Where the dish parks when its target sets and on `/go-home`; drive coordinates | Alt=90, Az=180 |
| Update Tolerance | Minimum position change to trigger update | 0.25 deg |
| Page Name | Web interface title | "SRT Controller" |
| AP SSID/Password | WiFi access point credentials | SRT_Controller/radio1420 |

Settings are saved to ESP32 flash (NVS) and persist across reboots.

The 10 degree observing horizon is enforced separately from the mechanical altitude lower limit. This keeps automatic tracking above local obstructions even if the saved mount minimum remains 0 degrees. The horizon is a true-frame test, made on the target's sky altitude before the pointing model; the mount limits are drive-frame and clamp after it.

The stow is held in **drive** coordinates and the pointing model is bypassed on the stow path: parking is mechanical, not an observation. At the zenith azimuth is degenerate and the model's `tan(alt)` azimuth term would ask for a ~50 degree correction that moves the beam by nothing. It is still clamped to the mount limits. The stow is unrelated to the Due's `HOMEALT`/`HOMEAZ` (`cfg.homeAlt/homeAz`), which are the encoder origin that the limit-switch stall corresponds to.

Galactic plane tracking uses a second, higher threshold. The controller walks outwards along b = 0 from the galactic centre and takes the first longitude at or above the acquisition altitude, preferring the higher of the two equidistant candidates because it stays observable longer. That is an acquisition floor, not a horizon: once tracking, the target is followed down until the 10 degree horizon parks the dish. At 45 degrees a suitable point exists about 73 percent of the time and never comes closer than roughly 45 degrees of longitude to the centre; lowering it to 30 degrees raises availability to about 94 percent.

---

## 4. Source Code Structure

### main.cpp

Main application entry point and tracking loop.

**Key Functions:**

- `setup()` - Initialize hardware, WiFi, web server; start the loop watchdog last
- `loop()` - Handle servers, update tracking, clock status
- `updateTracking()` - Convert RA/Dec to true Alt/Az, then to drive, send to Due
- `syncTimeNTP()` - Start SNTP, or restart it after a link change (non-blocking)

**Tracking Loop Behavior:**

1. Reads whatever the Due has sent on every loop pass (~100 Hz); polls `STATUS` and updates the target once a second
2. A `/stop/movement` hold suspends sends until it expires
3. For Sun, Moon and Galactic Plane targets, refreshes the RA/Dec every 30 seconds
4. Converts RA/Dec to **true** Alt/Az with the true site position
5. Horizon test in the true frame: below `horizonAlt` it sends the stow once (drive coordinates, model bypassed, clamped) and sets `waiting_for_rise`; tracking resumes when the target rises
6. Adds the operator's `/offset` in the true frame, applies az-only / alt-only axis holds
7. `trueToDrive()`: refraction, then the model terms
8. Drive azimuth outside the mount limits: holds and sets `waiting_for_wrap` until it comes back
9. Drive altitude above `mountAltMax`: holds in place (not driven to the stop) and sets `waiting_for_descend`
10. Clamps to the mount limits (the lower altitude stop) and sends with `sendDriveTarget()` if either axis moved by at least the deadband, drive against drive

Every state change (parking, wrap, descend, resume, and every clearing of a live target with the endpoint and client address) goes to the serial log through `logESP()`.

### coordinates.cpp

Astronomical coordinate transformations. All functions are pure.

| Function | Input | Output |
|---|---|---|
| `raDecToAltAz()` | RA (h), Dec (deg) | Alt, Az (deg) |
| `altAzToRaDec()` | Alt, Az (deg) | RA (h), Dec (deg) |
| `galacticToEquatorial()` | l, b (deg) | RA (h), Dec (deg) |
| `getSunPosition()` | (none) | RA (h), Dec (deg) |
| `getMoonPosition()` | (none) | RA (h), Dec (deg) |

### srt_serial.cpp

Serial communication with Arduino Due.

```cpp
srtSerial.sendDriveTarget(driveAlt, driveAz); // Drive coordinates only, "%.1f %.1f"
srtSerial.sendHome(); sendStop(); sendReset(); sendCalibrator(on);
srtSerial.requestStatus();        // "STATUS"
srtSerial.readStatus();           // Read and parse every waiting line
srtSerial.getCurrentAlt();        // Reported drive position
srtSerial.getStatusStr();         // Get status string
srtSerial.getHomingReportJSON();  // last_homing in /status
srtSerial.getDriveAckJSON();      // drive_ack in /status
srtSerial.logESP(msg);            // Serial log + diag RTC ring
```

The Due answers every drive target with `ACK DRIVE <alt> <az>` (the target
rounded to the 0.5 degree pulse grid) or `ERR DRIVE fault|homing|limits`, and an
unparseable line with `ERR UNKNOWN <line>`. A target unanswered after 2 s is
sent once more; a second silence counts as lost. Re-sending starts only once
an ACK has been seen, so a Due flashed before 2026-09-30 is left alone. A
mid-homing refusal arrives as `Homing: busy - ignored` and counts as refused.

The serial log is a 30-entry RAM ring (`TX`, `RX`, `ESP` entries), served by
`/serial/log`.

### pointing.cpp

The boundary between the two frames. **True** Alt/Az is where the dish looks on
the sky; **drive** is what the mount mechanically is (encoder pulses, 0.5
degree grid). The Due works only in drive coordinates.

```cpp
trueToDrive(trueAlt, trueAz, driveAlt, driveAz); // refraction, then model terms
driveToTrue(driveAlt, driveAz, trueAlt, trueAz); // three-pass fixed-point inverse of trueToDrive
driveAltWithinLimits(a); driveAzWithinLimits(z); clampToMountLimits(a, z);
refractionDeg(trueAlt);           // Bennett x 1.15 (radio), applied with or without a model
```

Model terms: `IE`, `IA`, `AN`, `AE`, `CA`, `NPAE`, `TF` (degrees) and
`AZSCALE` (degrees per degree). All default to zero; no model loaded is the
identity transform plus refraction. Every goto, track and manual move goes
through `trueToDrive()` before `sendDriveTarget()`; every measured position
(`/status` RA/Dec and l/b, Stellarium) goes through `driveToTrue()` first. The
model is stored in its own NVS namespace, so `/settings/reset` does not discard
it.

### diag.cpp

A record in `RTC_NOINIT` memory that survives every reset except a power
cycle: the loop stage last entered, uptime, time since the last target sent,
longest loop pass, heap low-water marks, and a ring of the last 24 `logESP`
events. At boot the previous record becomes `previous_boot` in `/diag`, with
the reset reason (panic, task watchdog, brownout, power-on, software).

The loop task is on the task watchdog at **30 s** (not the core's 5 s:
`readStringUntil` timeouts and WiFi power changes legitimately take seconds).
It is fed from the OTA `onProgress` callback, since an upload runs inside one
loop pass.

### sync.h

One recursive mutex (`SRTLock`) guards the state shared between `loopTask`
(tracking, Due serial, clock) and `async_tcp` (web handlers, Stellarium). The
wait is bounded at 2 s; on timeout the caller proceeds unlocked and
`lock_timeouts` in `/status` counts it.

### settings.cpp

Runtime settings with NVS persistence.

```cpp
settings.load();              // Load from NVS (called in setup)
settings.save();              // Save to NVS
settings.resetToDefaults();   // Reset to compile-time defaults
```

---

## 5. HTTP API

All endpoints return JSON unless noted.

### Status Endpoints

| Endpoint | Method | Description |
|---|---|---|
| `/` | GET | Web interface (HTML) |
| `/ping` | GET | Minimal plain-text liveness check (`ok`) |
| `/network` | GET | Minimal diagnostics for heap, active IPs and the lwIP resolver (issue #11) when the full UI is hard to load |
| `/status` | GET | Mount position and status |
| `/diag` | GET | This boot's and the previous boot's diagnostic record, reset reason, watchdog state. Lock-free: answers even with the loop stuck holding the lock |
| `/serial/log` | GET | Last 30 serial log entries (`time`, `dir` TX/RX/ESP, `msg`) |
| `/tracking` | GET | Current tracking state, including `waiting_for_rise`, `waiting_for_wrap`, `waiting_for_descend`, offsets |
| `/ephemeris` | GET | Sun, Moon and galactic-plane target (`sun`, `moon`, `plane`) |
| `/pointing` | GET | Pointing model in force |
| `/time/status` | GET | Time sync status |
| `/settings` | GET | Current settings (AP password not served) |

**Example: `/status` response**

```json
{
  "alt": 45.00,
  "az": 180.00,
  "true_alt": 44.87,
  "true_az": 181.24,
  "pointing_loaded": true,
  "ra": 12.3456,
  "dec": 45.67,
  "gal_l": 120.00,
  "gal_b": 30.00,
  "target_alt": 45.00,
  "target_az": 180.00,
  "alt_current_a": 0.15,
  "az_current_a": 0.20,
  "status": "Ready",
  "fault": "",
  "fault_active": false,
  "is_slewing": false,
  "calibrator": false,
  "clock_state": "ok",
  "clock_age_s": 1200,
  "lock_timeouts": 0,
  "serial_splices": 0,
  "malformed_status": 0,
  "last_homing": {
    "alt_error_first_deg": -0.5,
    "az_error_first_deg": -1.0,
    "alt_error_second_deg": null,
    "az_error_second_deg": null,
    "reapproach_skipped": true,
    "utc": 1787825741
  },
  "drive_ack": {
    "ack_seen": true,
    "acks": 412,
    "refused": 0,
    "resends": 0,
    "lost": 0,
    "unknown_commands": 0,
    "pending": false,
    "last_refusal": null
  },
  "uptime_s": 86400,
  "boot": 7,
  "reset_reason": "software (restart or OTA)",
  "loop_age_ms": 4,
  "free_heap": 180000,
  "raw": "Alt:45.0 Az:180.0 Ialt:0.1A Iaz:0.2A Status:Ready"
}
```

`alt`/`az` are the Due's reported **drive** position — the frame the
scheduler's slew check and `sun_scan.py` need. `true_alt`/`true_az` are the sky
position it corresponds to (`driveToTrue()`), and `ra`/`dec` and
`gal_l`/`gal_b` are computed from those. `target_alt`/`target_az` are the
Due's drive target. `pointing_loaded` is false when no model is stored (the
transform is then refraction only).

`clock_state` is `ok`, `stale` (no SNTP sync for 5 h), `unverified` (set from a
browser, never by SNTP) or `never`; `clock_age_s` is -1 before the first sync.
`lock_timeouts` counts cross-task lock acquisitions that timed out; it should
stay at zero. `serial_splices` counts lines from the Due that were neither a
status line nor a homing line (issue #34); `malformed_status` currently reports
the same counter. `drive_ack` is described under `srt_serial.cpp`; `lost`
should stay at zero. `uptime_s`, `boot`, `reset_reason`, `loop_age_ms` and
`free_heap` are enough to notice a reboot or a hung loop from a poll; `/diag`
has the rest. `raw` is the last status line as received.

`last_homing` is the encoder error the Due reports at the last homing (issue
#24), latched from its `Homing: <axis> limit reached at N pulses (D deg)`
lines. The **first approach** is a fixed switch-detection offset plus any
count drift since the previous homing. The offset is normally −2.0 to +0.5°
(most often alt −1.0°, az −0.5°, however recently the mount was homed), so
only a reading outside that range is drift; the field names say `error` for
historical reasons. The **re-approach** after the 5° back-off is the stop's
repeatability, when there is one: the Due skips it when both axes met their
switches at creep and the azimuth cut edge was captured (issue #33), prints
`Re-approach skipped`, and the second-approach values are then `null` with
`reapproach_skipped: true`. `last_homing` is `null` until a homing has run. The
value is latched here because the status flood during a homing scrolls the
line out of the 30-line serial log before a reader can poll it.

**Example: `/diag` response** (events abridged)

```json
{
  "reset_reason": "task watchdog",
  "loop_watchdog": true,
  "free_heap": 180000,
  "max_alloc": 110000,
  "loop_age_ms": 3,
  "this_boot": { "boot": 8, "uptime_s": 60, "last_stage": "loop delay", "last_target_age_s": null,
                 "max_loop_gap_ms": 40, "min_free_heap": 170000, "min_max_alloc": 100000,
                 "events": ["+5s NTP synced (first since boot)"] },
  "previous_boot": { "boot": 7, "uptime_s": 86400, "last_stage": "tracking: reading the Due",
                     "last_target_age_s": 31, "max_loop_gap_ms": 450, "min_free_heap": 120000,
                     "min_max_alloc": 60000,
                     "events": ["14:09:11 Tracking Sun cleared by /stop/all from 192.168.50.1"] }
}
```

`last_stage` is the loop stage last entered, so after a watchdog reset it names
where the loop hung. `last_target_age_s` is the time since tracking last sent a
target (`null` if none this boot). Events carry UTC once the clock is set,
`+Ns` since boot before that.

`previous_boot` is `null` after a power cycle, which clears RTC memory.

### Control Endpoints

| Endpoint | Parameters | Description |
|---|---|---|
| `/goto` | `ra`, `dec`, optional `track=0` | Go to RA/Dec (J2000). Default tracks (historical goto-implies-tracking); `track=0` slews once and stops, and returns 400 if the drive position is outside the mount limits. The UI's Go To sends `track=0` |
| `/goto/galactic` | `l`, `b`, optional `track=0` | As `/goto`, for galactic coords; returns the RA/Dec |
| `/track/radec` | `ra`, `dec` | Track RA/Dec (J2000) |
| `/track/galactic` | `l`, `b` | Track galactic coords |
| `/track/galactic-plane` | (none) | Track the galactic-plane point nearest the centre above `galacticMinAlt`; 409 if none exists now. Target name `Galactic Plane`, re-chosen every 30 s |
| `/track/sun` | (none) | Track Sun |
| `/track/moon` | (none) | Track Moon (topocentric) |
| `/tracking/enable` | `enable=0/1` | Enable tracking of the current target, or stop tracking and clear it |
| `/tracking/axis` | `mode=both/az/alt`, optional `alt` or `az` | Track both axes or hold one axis fixed |
| `/direct` | `alt`, `az` | Go to a **true** Alt/Az: clears tracking, applies `trueToDrive()`, returns `drive_alt`/`drive_az`, or 400 if outside the mount limits. With az-only or alt-only tracking active it sets the held axis instead (clamped) |
| `/go-home` | (none) | Clear tracking and drive to the stow, in drive coordinates with the pointing model bypassed, clamped to the mount limits. Returns `drive_alt`/`drive_az` |
| `/stop/movement` | (none) | Stop current motion and hold automatic tracking sends for 10 seconds |
| `/stop/slewing` | (none) | Same as `/stop/movement` |
| `/stop/tracking` | (none) | Clear the tracking target without sending a motion stop |
| `/stop/all` | (none) | Stop motion and clear the current tracking target |
| `/reset` | (none) | Clear an active Due fault; 409 if none is active |
| `/home` | (none) | Clear tracking and run the Due homing sequence |
| `/offset` | `alt`, `az` | Set the operator's pointing offset (degrees, true frame, on top of the model) |
| `/offset/clear` | (none) | Clear pointing offset |

All goto and track endpoints except `/track/sun`, `/track/moon` and
`/track/galactic-plane` refuse a target below `horizonAlt` with 400 before
changing any state. Every clearing of a live tracking target is logged with the
endpoint and the client address.

### Pointing Endpoints

| Endpoint | Method | Description |
|---|---|---|
| `/pointing` | GET | Model in force: `loaded`, `version`, `n_scans`, `fitted_utc`, `terms` |
| `/pointing/apply` | POST | Replace the model from a JSON document in the body, save to NVS |
| `/pointing/clear` | GET | Zero the model and erase it from NVS |

`/pointing/apply` takes the document the scheduler builds
(`sun_scan.pointing_model_document()`):

```json
{"version": 1, "fitted_utc": "2026-09-23T12:00:00Z", "n_scans": 14,
 "frame": "cross_elevation",
 "terms": {"IE": -1.2, "IA": 0.5, "AN": 0.1, "AE": -0.1, "CA": -1.4, "AZSCALE": 0.0036}}
```

The controller reads `version`, `n_scans`, `fitted_utc` and `terms`; other
keys (`frame`, `site`, `residual_rms_deg`) are carried for the record and
ignored. Missing or malformed `version`, a version below 1, no `terms` object, no recognised term, a
malformed number or a term outside its plausible range rejects the whole
document with 400 and leaves the current model in force. Unknown term names are
ignored. Bodies over 1536 bytes are refused with 413. The response carries the
model as stored.

### Settings Endpoints

| Endpoint | Description |
|---|---|
| `/settings` | GET current settings |
| `/settings/save` | Save settings (query params: `observer_lat`, `observer_lon`, `mount_az_min/max`, `mount_alt_min/max`, `horizon_alt`, `galactic_min_alt`, `stow_alt`, `stow_az`, `position_deadband`, `ap_ssid`, `ap_password`, `page_name`) |
| `/settings/reset` | Reset to defaults (the pointing model is kept) |

### Time Endpoints

| Endpoint | Parameters | Description |
|---|---|---|
| `/time/status` | (none) | Clock state, see section 8 |
| `/time/sync` | (none) | Restart the SNTP client now; returns at once, the result appears in `/time/status` |
| `/time/set` | `timestamp` (Unix s) | Set the clock from a browser. Source becomes `browser`; `lastSyncEpoch` is not touched, so a clock that SNTP has never synced this boot reads `unverified` |

### Network Endpoints

| Endpoint | Description |
|---|---|
| `/wifi/status` | Network status (includes WiFi, Ethernet, MAC addresses) |
| `/wifi/scan` | Scan for WiFi networks |
| `/wifi/connect` | Connect to WiFi network |
| `/wifi/forget` | Forget saved WiFi credentials |
| `/wifi/power` | Enable/disable WiFi (`enable=0/1`) - requires Ethernet connection |
| `/eth/save` | Save Ethernet settings (dhcp, ip, gateway, subnet, dns) |

The `/wifi/status` response includes hostname, mDNS URL, OTA status, `wifi_enabled`, `eth_mac` and `wifi_mac` fields.

---

## 6. Stellarium Protocol

The controller implements the Stellarium telescope protocol on TCP port 10001.

### Stellarium Setup

1. **Configuration > Plugins > Telescope Control**
2. Enable plugin and restart Stellarium
3. Add telescope:
   - Type: "External software or remote computer"
   - Host: ESP32 IP address (normally `192.168.50.120`; AP fallback `192.168.4.1`)
   - Port: `10001`
4. Connect
5. Select any object and press `Ctrl+1` to slew

### Coordinate Handling

- Stellarium sends **J2000** coordinates
- A goto becomes an ordinary tracking target (unnamed RA/Dec); there is no horizon check at the goto, so a target below `horizonAlt` parks at the stow through the tracking loop
- Position reports, every 100 ms, are where the dish **is**: the Due's measured drive position, brought to true Alt/Az with `driveToTrue()`, then to J2000 RA/Dec. Not the commanded target

---

## 7. Coordinate System

### Reference Frame

All equatorial coordinates use **J2000** (epoch J2000.0, equinox J2000.0):

- Standard for modern star catalogs
- Used by Stellarium, SIMBAD, and most planetarium software

### Precession

The controller applies IAU 1976 precession to convert J2000 coordinates to the equinox of the current date before computing Alt/Az.

### True and Drive Frames

Everything astronomical is computed in the **true** frame with the true site
latitude and longitude. `trueToDrive()` converts a true position to the
**drive** frame the Due works in: radio refraction first (applied whether or
not a model is loaded; `sun_scan.refraction_deg()` must stay identical to
`refractionDeg()`), then the model terms. `driveToTrue()` inverts it. The
observing horizon is tested before the transform, the mount limits after it,
and arrival checks stay wholly in the drive frame. See `pointing.h`.

### Sun and Moon

Sun and Moon positions are calculated using simplified algorithms:

- **Sun accuracy:** ~1 arcmin
- **Moon:** topocentric since 2026-09-07 (Meeus ch. 40 parallax, issue #3 C14); agrees with pyephem to 0.025 deg. Before that it was geocentric and up to ~1 deg out

---

## 8. Time Synchronization

Accurate UTC time is required for coordinate transforms.

### NTP (Primary)

The lwIP SNTP client runs in the background; nothing blocks on it. It is
started once, on the first link up:

```cpp
esp_sntp_set_time_sync_notification_cb(onTimeSync);
esp_sntp_set_sync_interval(NTP_SYNC_INTERVAL_MS);   // hourly
configTime(0, 0, NTP_SERVER, NTP_SERVER_FALLBACK);   // pool.ntp.org, 162.159.200.123
```

The numeric fallback keeps the clock syncing when DNS fails, so `"source":"NTP"`
proves the clock synced, not that name resolution works. An Ethernet link-up
restarts the client (`esp_sntp_restart()`); a clock that has never synced this
boot is restarted every 5 min. Success is declared only by `onTimeSync()`, when
SNTP has actually set the clock: a soft reset keeps the RTC running, so a
plausible-looking time after boot proves nothing. Each resync records the
correction it applied (`last_offset_ms`) as a drift diagnostic. After 5 h with
no sync the controller logs a warning; tracking is never blocked.

Proof that the link's NAT works is a fresh sync after a reboot: `sync_count` 1
with a small `last_sync_age_s`.

### Browser Fallback

If `/time/status` reports `synced: false`, the web interface sends browser
time on page load (`/time/set`). A browser-set clock reports `unverified`.

### Time Status

Check via `/time/status`:

```json
{
  "synced": true,
  "source": "NTP",
  "sync_state": "ok",
  "stale": false,
  "last_sync_age_s": 1200,
  "last_offset_ms": -12,
  "sync_count": 25,
  "utc": "2026-09-30 14:30:00",
  "timestamp": 1790778600
}
```

`sync_state` is `ok`, `stale`, `unverified` or `never`. `last_sync_age_s` is -1
before the first SNTP sync; `stale` is true then as well. `last_offset_ms` is 0
for the first sync of a boot.

---

## 9. Networking

### Network Modes

The ESP32 operates in **AP+STA** mode:

1. **WiFi Access Point** - Active at 192.168.4.1 (can be disabled); the fallback when Ethernet is unreachable
2. **WiFi Station** - Connects to saved network if available
3. **Ethernet** - Native WT32-ETH01 LAN with DHCP or static address

### The Private Link

The controller is not on the observatory LAN. Its Ethernet goes to a TP-Link
TG-3468 (`enp5s0`) in the observatory computer, NetworkManager connection
`srt-link`, `ipv4.method shared`, host at `192.168.50.1/24`. Shared mode
supplies the address, DHCP/DNS and the NAT the controller needs to reach
`pool.ntp.org`. The controller stays on **DHCP**; its address is pinned by MAC
on the host in `/etc/NetworkManager/dnsmasq-shared.d/srt.conf`
(`dhcp-host=70:4B:CA:58:59:8B,192.168.50.120`). Nothing on the controller is
configured for the link, so moving the cable back to a campus switch reverses
it. Other machines on the observatory LAN cannot reach it. Build procedure:
`docs/OBSERVATORY_HOST_SETUP.md`.

### Startup Sequence

1. Load settings and the pointing model from NVS; open the Due UART
2. Initialize Ethernet, wait up to 5 s for a lease; on link up start SNTP
3. Always start the WiFi Access Point, then try saved station credentials (15 s timeout)
4. Restore the DNS resolver if WiFi startup cleared it (issue #11; checked every loop pass thereafter)
5. Start the web server, mDNS, OTA and the Stellarium server; arm the loop watchdog

### IP Addresses

| Interface | IP Address |
|---|---|
| Private link Ethernet | `http://192.168.50.120/` |
| Hostname | `http://srt-controller.local/` |
| WiFi AP | 192.168.4.1 (fixed) |
| WiFi Station | DHCP assigned |
| Ethernet (WT32-ETH01) | DHCP (reserved by MAC on the host) or static |

### Ethernet Configuration (WT32-ETH01)

Ethernet IP can be configured via the web interface Network tab:

- **DHCP** (default, and the normal mode): address from the host's reservation
- **Static IP**: Manually configure IP, gateway, subnet, and DNS. The form is pre-filled with `192.168.50.120` / gateway and DNS `192.168.50.1` / `255.255.255.0`, the link the controller is on

Settings are stored in non-volatile memory (NVS) and persist across reboots.
Changes require a reboot to take effect.

### WiFi Power Control

When Ethernet is connected, WiFi can be disabled to save power (~80-120mA):

- **Web UI**: Network tab > WiFi Power > Disable WiFi
- **API**: `GET /wifi/power?enable=0`

The radio change is queued for the loop and the request answers at once
(`pending: true`). The setting is **not** persisted: WiFi and the AP come back
on every boot, which keeps `192.168.4.1` as the fallback path. WiFi cannot be
disabled unless Ethernet is connected.

---

## 10. Development

### Serial Monitor

The WT32-ETH01 has no USB port; its console is UART0 on TX0/RX0, reached with
the temporary FT232 programmer.

```bash
~/.platformio/penv/bin/pio device monitor -b 115200
```

In normal running the serial log (`/serial/log`) and `/diag` are the
controller's record, and the Due's Native USB port mirrors the ESP32-to-Due
command traffic (see `WT32_ETH01_MIGRATION.md` section 6).

### Debug Output

```cpp
#define DBG(x) if (Serial) { x; }
DBG(Serial.println("Debug message"));
```

The guard was for the ESP32-S3's USB CDC, which blocked without a host
attached. On the WT32-ETH01 `Serial` is a plain UART and the guard is always
true; output goes to TX0 whether or not anything is listening.

### Memory Usage

Typical usage: ~42% flash, ~14% RAM on WT32-ETH01 (ESP32 with 4MB flash).

### Building

```bash
PIO=~/.platformio/penv/bin/pio   # Windows: ~/.platformio/penv/Scripts/pio.exe

# Build only (wt32-eth01 is the default environment)
$PIO run

# Build and upload over Ethernet
$PIO run -e wt32-eth01-ota --target upload

# Host unit tests
$PIO test -e native

# Clean build
$PIO run --target clean
```

The `native` environment builds only `coordinates.cpp` and `pointing.cpp`
(`build_src_filter`) with `test/shim/` standing in for the Arduino headers, so
the firmware source is tested exactly as it is flashed.

---

## 11. Troubleshooting

### Web Interface Issues

| Problem | Solution |
|---|---|
| Can't connect to 192.168.50.120 | Reachable only from the observatory computer. Check the `srt-link` connection on `enp5s0`, the cable and controller power; try `/ping` or `/network`, or the AP at 192.168.4.1 |
| Can't connect to 192.168.4.1 | Verify connected to SRT_Controller WiFi |
| Page loads but no data | Check Due serial connection |
| Settings won't save | Check NVS, try reset to defaults |

### Coordinate Issues

| Problem | Solution |
|---|---|
| Position doesn't match sky | Check observer lat/lon in settings (the true site, never a correction) and `/pointing` |
| Large errors (>1 deg) | Check time sync status |
| `pointing_loaded: false` | No model stored (cleared, or flash erased); the transform is refraction only. Re-apply the model from the scheduler |

### Stellarium Issues

| Problem | Solution |
|---|---|
| Can't connect | Check IP and port 10001 |
| Connects but no slew | Click object then Ctrl+1 |
| Wrong position shown | Verify time is synced |

### Serial Issues

| Problem | Solution |
|---|---|
| No status updates | Check TX/RX wiring (cross-connect) |
| Garbled data | Verify baud rate (115200) |
| `serial_splices` rising | Due replies arriving faster than read, or bytes lost on the link (issue #34) |
| `drive_ack.lost` non-zero | A drive target went unanswered twice; check `/serial/log` |
| Controller restarted unexpectedly | `/diag`: `reset_reason` and `previous_boot.last_stage` |

---

## Appendix: Quick Reference

### Default Credentials

| Setting | Value |
|---|---|
| WiFi AP SSID | SRT_Controller |
| WiFi AP Password | radio1420 |
| Private link Ethernet IP | 192.168.50.120 |
| AP IP | 192.168.4.1 |
| Web Port | 80 |
| Stellarium Port | 10001 |

### Pin Assignments (WT32-ETH01)

| Function | GPIO |
|---|---|
| Due TX | 4 |
| Due RX | 14 |
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

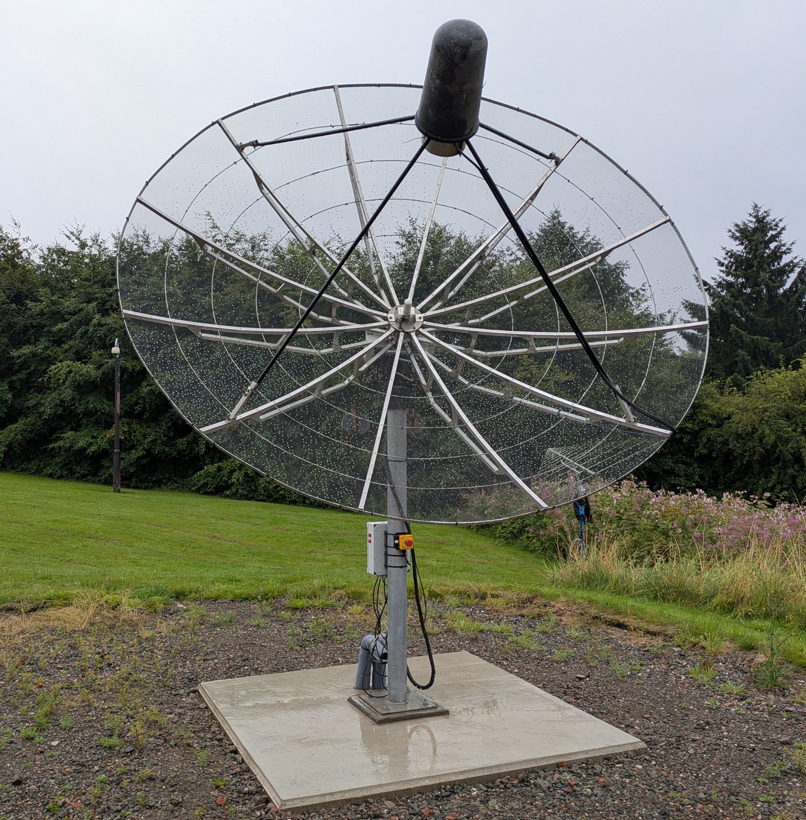
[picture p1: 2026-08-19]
docs/figures/srt_dish.jpg

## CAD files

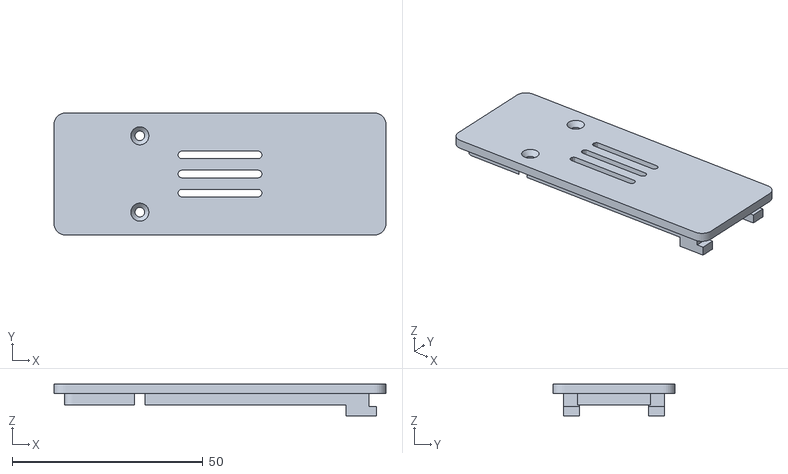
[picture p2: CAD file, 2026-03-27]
enclosure/wt32_eth01_enclosure_lid.stl
87.0 x 32.0 x 8.30

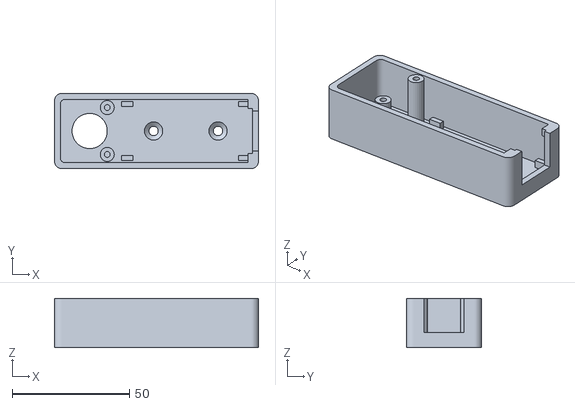
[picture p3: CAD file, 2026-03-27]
enclosure/wt32_eth01_enclosure_base.stl
87.0 x 32.0 x 21.1

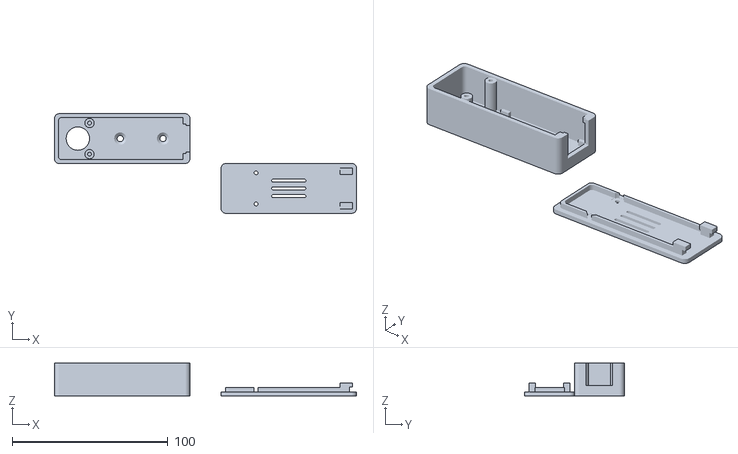
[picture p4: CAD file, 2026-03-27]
enclosure/wt32_eth01_enclosure.stl
194.0 x 64.0 x 21.1

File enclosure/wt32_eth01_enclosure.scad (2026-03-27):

// WT32-ETH01 Enclosure for External Box Mounting
// Designed to mount on outside of larger enclosure with wire feedthrough

// ============================================
// PARAMETERS - Adjust these to fit your needs
// ============================================

// WT32-ETH01 Board Dimensions (measure your board!)
// Note: Board is ~55mm long x 25mm wide, but pin headers add ~1mm each side
board_length = 55;      // Length of PCB (mm)
board_width = 25;       // Width of PCB (mm) - actual PCB width
board_thickness = 1.6;  // PCB thickness (mm)
component_height = 13;  // Height of tallest component (Ethernet jack ~13.5mm)

// Enclosure Parameters
wall_thickness = 2.5;           // Wall thickness
clearance = 1.0;                // Clearance around board
extension_length = 25;          // Extra length for wire routing and screw posts
wire_hole_diameter = 15;        // Diameter of wire feedthrough hole

// Floor mounting holes (countersunk, under the board)
floor_mount_hole_diameter = 4;      // Hole for self-tapping screw shaft
floor_mount_countersink = 8;        // Countersink diameter (for screw head)
floor_mount_countersink_depth = 2;  // Countersink depth

// Lid parameters
lid_lip_height = 3;             // Height of lid overlap lip
lid_tolerance = 0.3;            // Tolerance for lid fit

// Ethernet port cutout (RJ45 connector is narrower than board)
eth_port_width = 16;            // Standard RJ45 width (~16mm)
eth_port_height = 13.5;         // Standard RJ45 height (~13.5mm)
eth_port_clearance = 0.5;       // Extra clearance around connector

// Screw post parameters for lid
screw_post_diameter = 6;
screw_hole_diameter = 2.5;      // For M3 self-tapping screws
screw_post_height = 3;

// Board support rail height
rail_height = 3;

// ============================================
// CALCULATED VALUES
// ============================================

// Internal dimensions
// No extra length at Ethernet end - RJ45 will be flush with end wall
internal_length = board_length + extension_length + clearance * 2;
internal_width = board_width + clearance * 2;
// Height: rails + board + components + clearance above
internal_height = rail_height + board_thickness + component_height + clearance;

// Board position (for reference)
board_start_x = wall_thickness + extension_length + clearance;
board_end_x = board_start_x + board_length;

// External dimensions (box only, not including flanges)
external_length = internal_length + wall_thickness * 2;
external_width = internal_width + wall_thickness * 2;
external_height = internal_height + wall_thickness;  // No top wall (lid goes there)

// ============================================
// MODULES
// ============================================

// Rounded box helper
module rounded_box(length, width, height, radius) {
    hull() {
        for (x = [radius, length - radius]) {
            for (y = [radius, width - radius]) {
                translate([x, y, 0])
                    cylinder(r=radius, h=height, $fn=32);
            }
        }
    }
}

// Main enclosure base
module enclosure_base() {
    corner_radius = 3;

    // Screw post positions - only at back (wire) end, 2 posts total
    post_x = wall_thickness + extension_length - screw_post_diameter/2 - 2;
    post_y_inset = wall_thickness + screw_post_diameter/2 + 0.5;

    union() {
        difference() {
            // Main box body
            rounded_box(external_length, external_width, external_height, corner_radius);

            // Hollow out the interior
            translate([wall_thickness, wall_thickness, wall_thickness])
                rounded_box(internal_length, internal_width, internal_height + 1, corner_radius - 1);

            // Floor mounting holes - countersunk, positioned under the board
            // Two holes spaced along the board length
            floor_mount_x1 = board_start_x + board_length * 0.25;
            floor_mount_x2 = board_start_x + board_length * 0.75;
            floor_mount_y = external_width / 2;

            for (x = [floor_mount_x1, floor_mount_x2]) {
                // Through hole for screw shaft
                translate([x, floor_mount_y, -1])
                    cylinder(d=floor_mount_hole_diameter, h=wall_thickness + 2, $fn=24);
                // Countersink from inside (top of floor)
                translate([x, floor_mount_y, wall_thickness - floor_mount_countersink_depth])
                    cylinder(d1=floor_mount_hole_diameter, d2=floor_mount_countersink,
                             h=floor_mount_countersink_depth + 0.1, $fn=24);
            }

            // Wire feedthrough hole (at extension end, through bottom)
            translate([wall_thickness + extension_length/2, external_width/2, -1])
                cylinder(d=wire_hole_diameter, h=wall_thickness + 2, $fn=48);

            // Ethernet port cutout - flush with end wall
            // The RJ45 jack (~16mm wide) is narrower than the board (~25mm) and centered
            eth_cutout_width = eth_port_width + eth_port_clearance * 2;
            eth_cutout_height = eth_port_height + eth_port_clearance * 2;
            eth_y = (external_width - eth_cutout_width) / 2;  // Centered in enclosure width
            eth_z = wall_thickness + rail_height + board_thickness - eth_port_clearance;  // Board on rails
            // Cut through the end wall - RJ45 flush with outside
            translate([external_length - wall_thickness - 1, eth_y, eth_z])
                cube([wall_thickness + 2, eth_cutout_width, eth_cutout_height]);
        }  // end difference for main box

        // Screw posts - only 2 at the back (wire) end
        for (y = [post_y_inset, external_width - post_y_inset]) {
            difference() {
                translate([post_x, y, wall_thickness])
                    cylinder(d=screw_post_diameter, h=external_height - wall_thickness, $fn=24);
                // Screw hole in post
                translate([post_x, y, external_height - 12])
                    cylinder(d=screw_hole_diameter, h=13, $fn=24);
            }
        }
    }  // end union

    // Board support rails - short sections at each end for pin clearance
    rail_width = 2;
    rail_stub_length = 5;  // Short stubs at each end

    // Front stubs (wire routing end of board)
    translate([board_start_x, wall_thickness + clearance, wall_thickness])
        cube([rail_stub_length, rail_width, rail_height]);
    translate([board_start_x, external_width - wall_thickness - clearance - rail_width, wall_thickness])
        cube([rail_stub_length, rail_width, rail_height]);

    // Rear stubs (Ethernet end of board)
    translate([board_end_x - rail_stub_length, wall_thickness + clearance, wall_thickness])
        cube([rail_stub_length, rail_width, rail_height]);
    translate([board_end_x - rail_stub_length, external_width - wall_thickness - clearance - rail_width, wall_thickness])
        cube([rail_stub_length, rail_width, rail_height]);

    // Lid retention lips at Ethernet end - on either side of the Ethernet cutout
    // These overhang inward for the lid tongue to slip under
    lip_overhang = 2;       // How far the lip extends inward
    lip_thickness = 3;      // Doubled for stronger retention    // Thickness of the lip
    lip_width = 8;          // Width of each lip section
    eth_cutout_width = eth_port_width + eth_port_clearance * 2;
    eth_y_start = (external_width - eth_cutout_width) / 2;
    eth_y_end = eth_y_start + eth_cutout_width;

    // Left lip (low Y side of Ethernet)
    translate([external_length - wall_thickness - lip_overhang,
               wall_thickness,
               external_height - lip_thickness])
        cube([lip_overhang, eth_y_start - wall_thickness - 1, lip_thickness]);

    // Right lip (high Y side of Ethernet)
    translate([external_length - wall_thickness - lip_overhang,
               eth_y_end + 1,
               external_height - lip_thickness])
        cube([lip_overhang, external_width - eth_y_end - wall_thickness - 1, lip_thickness]);
}

// Lid module
module enclosure_lid() {
    corner_radius = 3;
    lid_height = wall_thickness + lid_lip_height;
    lip_ridge_thickness = 1.5;  // Thickness of the lip ridge

    // Outer dimensions match the box
    outer_length = external_length;
    outer_width = external_width;

    // Lip dimensions (fits inside the box)
    lip_length = internal_length - lid_tolerance * 2;
    lip_width = internal_width - lid_tolerance * 2;

    // Screw post position (must match base) - only 2 posts at back
    post_x = wall_thickness + extension_length - screw_post_diameter/2 - 2;
    post_y_inset = wall_thickness + screw_post_diameter/2 + 0.5;
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

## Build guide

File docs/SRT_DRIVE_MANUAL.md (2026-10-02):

# SRT Motor Driver - Operations Manual

**Version 1.2**
**Acre Road Observatory, Glasgow**

---

## Table of Contents

1. [Overview](#1-overview)
2. [Building and Uploading](#2-building-and-uploading)
3. [Hardware Connections](#3-hardware-connections)
4. [Serial Communication](#4-serial-communication)
5. [Status Messages](#5-status-messages)
6. [Commands](#6-commands)
7. [System States](#7-system-states)
8. [Fault Conditions](#8-fault-conditions)
9. [Startup and Homing](#9-startup-and-homing)
10. [Configuration](#10-configuration)
11. [Simulation Mode](#11-simulation-mode)
12. [Troubleshooting](#12-troubleshooting)

---

## 1. Overview

The SRT Motor Driver manages the alt-azimuth drive system for the Small Radio Telescope. It provides:

- Automatic homing on startup
- Position tracking via reed switch encoders (0.5 degree resolution)
- Smooth motion with acceleration/deceleration ramps
- Overcurrent and fault protection
- Serial interface for control and monitoring
- Simulation mode for testing without hardware

All positions are **drive coordinates**: encoder pulses counted from the lower limit switches, 2 per degree. Refraction and the pointing model are applied upstream by the ESP32 controller (`esp32_controller_arduino/src/pointing.cpp`); the Due knows nothing of the sky.

The firmware is `src/main.cpp`; its defaults are in `include/config.h`.

### Specifications

| Parameter | Value |
|---|---|
| Microcontroller | Arduino Due (ARM Cortex-M3) |
| Position Resolution | 0.5 degrees (2 pulses per degree) |
| Altitude Range | 0 to 90 degrees |
| Azimuth Range | 0 to 355 degrees |
| Position after homing | Alt 0, Az 0 (the lower limit switches) |
| Current Limit | 5 Amps (configurable) |
| Serial Baud Rate | 115200 |
| Firmware banner | v1.2 |

---

## 2. Building and Uploading

The project uses [PlatformIO](https://platformio.org/) for building and uploading. Two build environments are provided:

| Environment | Purpose | Build Flag |
|---|---|---|
| `due` | Real hardware (default) | None |
| `simulation` | Software-only testing | `-DSIMULATION_MODE` |

A change to the homing flow or to any in-loop motor control must build cleanly in both.

### 2.1 Prerequisites

- [PlatformIO CLI](https://docs.platformio.org/en/latest/core/installation.html) or [VS Code with PlatformIO extension](https://platformio.org/install/ide?install=vscode)
- USB cable (Programming Port on the Arduino Due)

`pio` is not on PATH on the observatory machines. Use `~/.platformio/penv/bin/pio` on the Linux host and `~/.platformio/penv/Scripts/pio.exe` on Windows in place of `pio` below.

### 2.2 Building for Real Hardware

```bash
pio run -e due
```

### 2.3 Uploading to the Arduino Due

```bash
pio run -e due --target upload
```

### 2.4 Building for Simulation Mode

```bash
pio run -e simulation
```

Upload the simulation firmware the same way:

```bash
pio run -e simulation --target upload
```

### 2.5 Switching Environments in VS Code

Click the **environment selector** in the PlatformIO toolbar at the bottom of the VS Code window. Choose `due` for real hardware or `simulation` for testing. All build, upload, and monitor commands will then use the selected environment.

### 2.6 Serial Monitor

```bash
pio device monitor
```

Or use the VS Code PlatformIO serial monitor button.

---

## 3. Hardware Connections

### 3.1 Arduino Due Pinout

| Function | Pin | Wire Color | Notes |
|---|-----|---|---|
| **Fault Flags** |
| Az Fault Flag 1 | 5 | Blue | Motor driver status |
| Az Fault Flag 2 | 4 | Purple | Motor driver status |
| Alt Fault Flag 1 | 7 | Blue | Motor driver status |
| Alt Fault Flag 2 | 6 | Purple | Motor driver status |
| **Motor Control** |
| Az PWM | 8 | Green | Speed control (inverted) |
| Az Direction | 9 | Yellow | Logical LOW=West, HIGH=East; pin level inverted (`AZ_DIR_INVERT`) |
| Alt PWM | 10 | Green | Speed control (inverted) |
| Alt Direction | 11 | Yellow | Logical LOW=Down, HIGH=Up; pin level inverted (`ALT_DIR_INVERT`) |
| **Driver Reset** |
| Az Reset | 22 | Black | HIGH=enabled |
| Alt Reset | 24 | White | HIGH=enabled |
| **Position Encoders** |
| Az Pulses | 12 | Yellow | Reed switch, rising edge |
| Alt Pulses | 13 | Blue | Reed switch, rising edge |
| **Current Sensors** | | | 44mV/A, bipolar, 3.3V ADC ref |
| Az Current | A1 | Black | Analog input |
| Alt Current | A0 | White | Analog input |
| **Calibrator** |
| Calibrator Control | 26 | --- | Output, active HIGH; drives nothing (section 6.5) |

Both motors are wired in reverse. `AZ_DIR_INVERT` and `ALT_DIR_INVERT` in `config.h` invert the level in software, so the direction pin is LOW when the firmware drives East/Up. Every write goes through the `AZ_DIR()` / `ALT_DIR()` macros.

### 3.2 USB Ports

The Arduino Due has two USB ports:

| Port | Location | Use |
|---|---|-----|
| **Programming Port** | Near DC jack | Programming + serial terminal (Due CLI) |
| **Native USB Port** | Near reset button | ESP32 serial bridge (monitoring ESP32 traffic) |

**Use the Programming Port** for uploading firmware and the Due's own serial terminal.

The **Native USB Port** forwards traffic between the PC and the ESP32 via Serial1. Every byte the ESP32 sends the Due is copied to it, and anything typed on it goes to the ESP32. It does not show the Due's own output.

> **Important:** The Native USB port uses USB CDC, which requires the host to assert DTR before data will appear. PlatformIO's serial monitor (`pio device monitor`) asserts DTR automatically. Tools like Termite and PuTTY do not, and will show no output. To monitor the Native USB port, use:
>
> ```
> pio device monitor -p COM<n> -b 115200
> ```

### 3.3 WT32-ETH01 Interface (Serial1)

The Due communicates with the WT32-ETH01 (ESP32) via hardware UART:

| Due Pin | Function | WT32-ETH01 Pin |
|---|---|---|
| 18 | TX1 (transmit) | IO14 (RX) |
| 19 | RX1 (receive) | IO4 (TX) |
| GND | Ground | GND |

**Note:** Both the Due and ESP32 operate at 3.3V logic - direct connection is used, no level shifter required. Avoid IO32/IO33 on WT32-ETH01 RS-485 variants (labelled CFG/485_EN).

### 3.4 Encoders

Each axis has one reed switch, 2 pulses per degree. The ISRs (`pulseAzISR`, `pulseAltISR`) are attached on the **RISING** edge (since commit 5b25734, 2026-05-12) and take the direction from the DIR pin at the moment of the pulse.

- **Runt filter:** the ISR waits 1 ms (`PULSE_MIN_WIDTH_US`) and drops the edge if the pin no longer reads HIGH.
- **Debounce:** a pulse is counted only if at least `DEBOUNCE` (az, 50 ms) or `DEBOUNCE_ALT` (alt, 100 ms) has passed since the last *accepted* pulse. The timestamp `lastPulseAz/Alt` is updated only on accepted pulses. Updating it on every edge once made the counter lose every pulse as the pulse period approached the window.
- The altitude window sits 28% under the full-speed pulse period (128 ms at 3.9 deg/s). Each homing limit line prints the ISR's statistics (`[enc: rejected ..., min accepted ..., max rejected ..., window ...]`).
- **Backlash:** after an azimuth direction change the first `BACKLASH` x 2 pulses are absorbed uncounted (default 0).

---

## 4. Serial Communication

### 4.1 Connection Settings

| Parameter | Value |
|---|---|
| Baud Rate | 115200 |
| Data Bits | 8 |
| Stop Bits | 1 |
| Parity | None |
| Line Ending | CR or LF or CRLF |

### 4.2 Output Format

Status line format. The ESP32 parser is positional: do not change it.

```
Alt:%.1f Az:%.1f Ialt:%.1fA Iaz:%.1fA Status:<state> [<fault>] -> Alt:%.1f Az:%.1f *HH
```

`[<fault>]` appears only in FAULT, `-> Alt Az` (the target) only while Slewing or Reversing. Every line ends in ` *HH`, the XOR of every character before the ` *` in hex; the controller rejects a line whose checksum fails, which is what catches a truncated or corrupted line. Until 2026-10-02 the line ended `Cal:ON|OFF` instead (issue #39), and the controller still accepts that ending.

```
Alt:45.0 Az:180.0 Ialt:0.0A Iaz:0.0A Status:Ready *7D
Alt:30.0 Az:150.0 Ialt:2.1A Iaz:1.9A Status:Slewing -> Alt:45.0 Az:180.0 *16
Alt:30.0 Az:150.0 Ialt:5.2A Iaz:0.0A Status:FAULT [Altitude motor overcurrent] *6E
```

**Fields:**

| Field | Description | Units |
|---|---|---|
| `Alt` | Current altitude position (counter / 2) | Degrees |
| `Az` | Current azimuth position (counter / 2) | Degrees |
| `Ialt` | Altitude motor current, signed (IIR filtered, ~1s settling) | Amps |
| `Iaz` | Azimuth motor current, signed and printed negated (IIR filtered, ~1s settling) | Amps |
| `Status` | System state | See section 5.1 |
| `Cal` | Calibrator pin state | ON/OFF |

Where it goes:

- **Programming port:** printed when the line less its currents differs from the last one printed, so once per 0.5 degree step while slewing and not on every current change. `STATUS` forces a print.
- **Serial1:** the full line, unsolicited, at most once per `STATUS_INTERVAL_MS` (1000 ms), and at once in answer to a `STATUS` received on Serial1.

### 4.3 Controller Protocol (Serial1)

The ESP32 sends the same commands as the programming port. The Due answers on Serial1 only with the lines below. Everything else (echoes, `Slewing to`, errors, `CONFIG`, `HELP`, `Homing: Backing off limits...`, `Homing complete`) goes to the programming port only.

| Event | Reply on Serial1 |
|---|---|
| Drive command accepted | `ACK DRIVE <alt> <az>`: the target as rounded to the 0.5 degree pulse grid |
| Drive command refused | `ERR DRIVE limits` (tested first), `ERR DRIVE fault`, `ERR DRIVE homing` |
| Line not recognised | `ERR UNKNOWN <line>` (first 24 characters) |
| `STATUS` | The status line, at once, on Serial1 only. The programming port's dedup buffer is not touched. |
| Unsolicited | The status line at most once a second |
| Homing progress | The `Homing:` lines marked (S1) in section 9.2 |

The ESP32 re-sends a target not acknowledged within 2 s once, counts a second silence as lost, and reports the counts as `drive_ack` in its `/status`. Commands are not checksummed: a digit lost on the wire in a drive target is obeyed. The ACK echoes the target as the Due understood it. Serial1 lines beginning `Alt:` are ignored (a looped-back status line).

**During a homing** the Due reads both ports on every loop pass (`homingServiceSerial`, issue #34):

- `STATUS` is answered with the live line.
- `STOP` aborts the homing into `FAULT_HOMING_ABORTED`. The programming port prints `Homing ABORTED: STOP received - position unknown, RESET then HOME`; the controller sees `Status:FAULT [Homing aborted by STOP - RESET then HOME]`.
- Anything else, drive targets included, is refused with `Homing: busy - ignored '<line>'` on the programming port and on the port it came from. Lines over 31 characters are dropped. `ERR DRIVE homing` is therefore not what a drive during a homing receives.

Commands never queue behind a homing.

---

## 5. Status Messages

### 5.1 System Status Values

| Status | Description |
|---|---|
| `Initializing` | System is starting up |
| `Homing` | Homing sequence running (also shown during `PROBE`) |
| `Ready` | Idle, waiting for commands |
| `Slewing` | Moving to target position |
| `Reversing` | An axis is ramping down and waiting for its coast to end before DIR flips |
| `FAULT` | Error condition - motors stopped |

### 5.2 Startup Messages

On power-up, the programming port shows the lines below. `<...>` stands for measured values. Status lines interleave with them and are omitted here, and the order of the two axes' limit lines depends on which stops first.

```
=================================
SRT Motor Driver v1.2
Acre Road Observatory, Glasgow
ESP32 Bridge: Native USB <-> Serial1
=================================

Type HELP for commands.

Calibrating current sensors...
  Az offset: <V>V
  Alt offset: <V>V
Starting homing sequence...
Homing: current zero re-measured at rest (shift az <A> A, alt <A> A)
Homing: Drive to limits...
Homing: Altitude limit reached at <n> pulses (<deg> deg) [enc: ...] I=<A>A
Homing: Azimuth limit reached at <n> pulses (<deg> deg) [enc: ...] I=<A>A det[...]
Homing: first approach - az cut edge not captured, az arrived at speed, alt arrived at speed
Homing: Backing off limits...
Homing: Re-approach limits...
Homing: Azimuth limit reached at <n> pulses (<deg> deg) [enc: ...] I=<A>A det[...]
Homing: Altitude limit reached at <n> pulses (<deg> deg) [enc: ...] I=<A>A
Homing: Az zero on the first edge after the current cut (cut <A>-><A> A, cut->edge <ms> ms, coast <n> pulses beyond it, reed HIGH at rest)
Homing: Alt zero on first edge (reed <HIGH|LOW> at rest, edge after <ms> ms, levels <levels>)
Homing: Moving to home position...

Homing complete. Position: Alt=0.0 Az=0.0
Ready. Type HELP for commands.
```

A boot homing starts its counter at 0 wherever the mount is, so it normally arrives at speed and takes the re-approach, as above. Section 9.2 gives every line.

In simulation mode, an additional banner line is shown:

```
=================================
SRT Motor Driver v1.2
Acre Road Observatory, Glasgow
*** SIMULATION MODE ***
ESP32 Bridge: Native USB <-> Serial1
=================================
```

### 5.3 Command Acknowledgments

When a valid drive command is received, the programming port shows:

```
Slewing to Alt:45.0 Az:200.0
```

preceded by `WARNING: Altitude|Azimuth xx.x outside software limits (min to max deg)` when the target is past a software limit but within the tolerance (section 6.7). A drive command from Serial1 is answered there with `ACK DRIVE` (section 4.3).

### 5.4 Error Messages

| Message | Cause |
|---|---|
| `ERROR: Cannot slew while in FAULT state. Power cycle to reset.` | Drive command in FAULT. `RESET` clears the fault; a power cycle is not needed. |
| `ERROR: Cannot home while in FAULT state. Power cycle to reset.` | `HOME` in FAULT. Send `RESET` first. |
| `Homing: busy - ignored '<line>'` | Any command other than `STATUS` or `STOP` during a homing |
| `ERROR: Altitude xx.x exceeds hardware limits (min to max deg)` | Alt outside the hardware limits |
| `ERROR: Azimuth xx.x exceeds hardware limits (min to max deg)` | Az outside the hardware limits |
| `ERROR: Altitude xx.x exceeds software limits + tolerance (min to max deg)` | Alt more than 4 degrees past a software limit |
| `ERROR: Azimuth xx.x exceeds software limits + tolerance (min to max deg)` | Az more than 4 degrees past a software limit |
| `Unknown command: X` then `Type HELP for commands.` | Unrecognised command word |
| `Usage: DRIVE <altitude> <azimuth>` | `DRIVE` without two numbers |
| `Usage: SET <parameter> <value>` / `ERROR: Unknown parameter 'X'` | Malformed `SET` |

---

## 6. Commands

All commands are case-insensitive.

### 6.1 Motion Commands

| Command | Description |
|---|---|
| `<alt> <az>` | Slew to position (e.g., `45.0 180.0`); the line must start with a digit, `-` or `.` |
| `DRIVE <alt> <az>` | Slew to position (explicit form) |
| `HOME` | Run the homing sequence (section 9.2). Refused in FAULT. |
| `STOP` | Stop both motors at once, no ramp. Prints `STOPPED`; no fault; the mount stays put until the next drive command. During a homing it aborts the homing into FAULT (section 4.3). |
| `RESET` | Clear a fault: prints `Fault cleared. Use HOME to re-home.` and returns to Ready with the counters unchanged. Otherwise prints `No fault to reset.` |

Targets are rounded to the nearest pulse (0.5 degree).

**Examples:**
```
45 180           Slew to Alt=45, Az=180
DRIVE 45.5 200   Slew to Alt=45.5, Az=200
HOME             Re-run homing sequence
STOP             Immediate stop
RESET            Clear fault (does not re-home: send HOME next)
```

### 6.2 Information Commands

| Command | Description |
|---|---|
| `STATUS` | Show current position and status |
| `CONFIG` | Show all configuration parameters |
| `HELP` or `?` | Show command help |

### 6.3 Configuration Commands

| Command | Description |
|---|---|
| `SET <param> <value>` | Set a configuration parameter (RAM only) |
| `SAVE` | Save configuration to flash memory |
| `LOAD` | Load configuration from flash memory (defaults if none is valid) |
| `DEFAULTS` | Reset to the `config.h` defaults (RAM only; `SAVE` to keep) |

**SET Parameters:**

*Hardware Limits (ends of travel, section 6.7):*

| Parameter | Description | Default | Units |
|---|---|---|---|
| `ALTHWMIN` | Altitude hardware minimum | 0 | degrees |
| `ALTHWMAX` | Altitude hardware maximum | 90 | degrees |
| `AZHWMIN` | Azimuth hardware minimum | 0 | degrees |
| `AZHWMAX` | Azimuth hardware maximum | 355 | degrees |

*Software Limits (operational, inside hardware limits):*

| Parameter | Description | Default | Units |
|---|---|---|---|
| `ALTMIN` | Altitude software minimum | 0 | degrees |
| `ALTMAX` | Altitude software maximum | 90 | degrees |
| `AZMIN` | Azimuth software minimum | 2 | degrees |
| `AZMAX` | Azimuth software maximum | 353 | degrees |

*Other Parameters:*

| Parameter | Description | Default | Units |
|---|---|---|---|
| `HOMEALT` | Altitude the axis drives to after zeroing, and reads there | 0 | degrees |
| `HOMEAZ` | Azimuth the axis drives to after zeroing, and reads there | 0 | degrees |
| `RAMPUP` | Acceleration time | 500 | ms |
| `RAMPDOWN` | Deceleration distance | 7 | degrees |
| `STOPRAMP` | Reversal deceleration time | 300 | ms |
| `CURRENT` | Overcurrent threshold | 5.0 | Amps |
| `STALL` | Stall detection timeout; also the pulse silence that marks a limit switch during homing | 2000 | ms |
| `DEBOUNCE` | Azimuth encoder debounce window | 50 | ms |
| `DEBOUNCE_ALT` | Altitude encoder debounce window | 100 | ms |
| `BACKLASH` | Azimuth backlash compensation (az only) | 0.0 | degrees |

`HOMEALT`/`HOMEAZ` are drive coordinates. The limit-switch zero is counter 0 whatever they are set to; they only move the mount off it at the end of a homing (section 9.2). Leave both at 0. They are unrelated to the controller's stow position (`settings.stowAlt/stowAz` on the ESP32).

**Examples:**
```
SET AZMAX 350        Set azimuth upper software limit to 350 degrees
SET CURRENT 4.5      Set current limit to 4.5 Amps
SET DEBOUNCE_ALT 100 Set altitude encoder debounce to 100 ms
SAVE                 Save changes to flash
CONFIG               Verify settings
```

### 6.4 Diagnostic Commands

Output goes to the programming port only.

| Command | Description |
|---|---|
| `XTRACE [s]` | Stream both raw current readings every loop for `s` seconds (default 60), with the zero offsets frozen at the moment of the command, so an offset the idle tracker would otherwise absorb stays visible. Header `XTRACE START ms rawAz rawAlt stateAz stateAlt posAz posAlt`, then `X ...` lines, then `XTRACE END`. Drive one axis meanwhile and watch the other's reading. |
| `PROBE [cycles]` | Azimuth limit-switch characterisation (issue #32), 1-12 cycles, default 3. Re-measures the current zero, then per cycle: creep out 3 degrees by count, settle 600 ms, creep in until pulses stop for 1 s, rest 800 ms. Ends 3 degrees out. Streams `t_ms,level,pos,raw_mA,phase` every 4 ms (phases `o`, `s`, `i`, `r`) between `PROBE START` and `PROBE END`. Start it with the azimuth near its lower limit: it does not drive there, and each creep is capped at 15 s. Altitude is untouched. Status reads `Homing` throughout; serial is not read, so `STOP` does not reach it. A driver fault or overcurrent aborts with `PROBE ABORTED: fault`. Refused in FAULT. |
| `TEST2` / `TEST2H` | Force Due pin 2 LOW / HIGH for a multimeter check (`Pin 2 forced LOW - measure with multimeter`). |

Building with `-DHOMING_TRACE` streams the azimuth creep of every homing on the programming port: `T <ms> <counter> <reed> <signed A> <armed><cut> <low count>`.

### 6.5 Calibrator Commands

Removed on 2026-10-02 (issue #39): the noise diode the `CAL` command switched was gone, and pin 26 is now simply held low. `CAL` is an unknown command.

### 6.6 Motion Profile

The system uses smooth motion profiles to prevent structural oscillation:

- **Start:** an axis leaves idle only when a drive command has set a new target (`executeDrive`). Stray encoder pulses while idle are not chased.
- **Acceleration:** linear ramp from `PWM_MIN_SPEED` (100) to full speed (0) over `RAMPUP` (default 500 ms)
- **Cruise:** Full speed
- **Deceleration:** quadratic ramp over `RAMPDOWN` (default 7 degrees = 14 pulses): PWM = 218 - (pulses remaining)^2, clamped to 0-100
- **Finish:** at the target count the PWM stops. After 50 ms the reed pin is sampled 10 times over 1 ms; if it is not steadily LOW the axis creeps at `PWM_MIN_SPEED` until it is, for at most 2 s.
- **Reversal:** a target on the other side ramps the PWM down linearly over `STOPRAMP` (default 300 ms). DIR flips only once no pulse has arrived for `REVERSAL_SETTLE_MS` (400 ms), bounded by `STOPRAMP` + the stall timeout. `Status:Reversing` covers the ramp and the wait. The ISR signs a pulse by the DIR pin, so a coast pulse after the flip would count backwards (issue #47, flashed 2026-09-24).

Commands can be sent at any time, even while moving. This enables smooth tracking of celestial sources with continuous position updates. Motion control runs only outside HOMING and FAULT.

### 6.7 Position Limits (Two-Tier System)

The controller uses a two-tier limit system for safe operation.

**Hardware Limits** (ends of travel):

| Axis | Minimum | Maximum |
|---|---|---|
| Altitude | 0 degrees, limit switch | 90 degrees, **encoder count only, no switch** |
| Azimuth | 0 degrees, limit switch | 355 degrees, limit switch |

The lower limit switches are microswitches that cut the motor current in the driving direction. They are not mechanical stop faces. The firmware sees one as pulses ceasing, and homing uses them as the encoder zero.

There is no switch at the altitude maximum. Every limit is a comparison against the counter, so all four constrain where the firmware *believes* the dish is. At the altitude maximum nothing else backs that up: after lost counts it has been exceeded (2026-08-21, found radiometrically hours later; issue #16). A target inside these limits is validated against the count, not safe by construction.

**Software Limits** (operational, inside hardware limits):

| Axis | Minimum | Maximum |
|---|---|---|
| Altitude | 0 degrees | 90 degrees |
| Azimuth | 2 degrees | 353 degrees |

Normal operation stays within software limits. In azimuth they leave a 2-degree margin from the hardware limits; in altitude they coincide.

**Software Limit Tolerance** (4 degrees, `SOFTWARE_LIMIT_TOLERANCE`):

A target up to 4 degrees beyond a software limit is accepted with a `WARNING`, but never beyond a hardware limit. Targets beyond software limits + tolerance are rejected.

---

## 7. System States

```
            boot               complete
   INIT ----------> HOMING ------------------> READY <--------+
                     ^  |                      |  ^           |
                HOME |  | fault, STOP    drive |  | arrived   | RESET
                     |  v                      v  |           |
                  READY FAULT <---- fault --- SLEWING         |
                        |                                     |
                        +-------------------------------------+
```

READY also goes to FAULT on a position-bounds or driver-flag fault. `RESET` returns FAULT to READY with the counters unchanged; `HOME` is refused until it has.

### State Descriptions

| State | Firmware state | Status string | Motors |
|---|---|---|---|
| **INIT** | `STATE_INIT` | `Initializing` | Stopped |
| **HOMING** | `STATE_HOMING` | `Homing` | Running |
| **READY** | `STATE_IDLE` | `Ready` | Stopped |
| **SLEWING** | `STATE_DRIVING` | `Slewing` or `Reversing` | Running |
| **FAULT** | `STATE_FAULT` | `FAULT` | Stopped |

---

## 8. Fault Conditions

When a fault occurs, the system immediately stops both motors and enters the FAULT state. The fault is reported in the status output. Outside a homing the main loop checks, in order: position bounds, driver fault flags, overcurrent, and (only while Slewing) stall. The homing loops run their own driver-flag and overcurrent checks (section 8.6) and no bounds check.

### 8.1 Motor Driver Faults

These are detected via the motor driver's fault flag pins. The flags are noisy at motor start and stop (inductive kickback, supply sag), so the same fault must persist for 5 consecutive checks (`FAULT_FLAG_PERSIST_COUNT`) before it is reported.

| Fault | Description | Likely Cause |
|---|---|---|
| `Azimuth motor short circuit` | FF1=LOW, FF2=HIGH | Wiring short, motor failure |
| `Altitude motor short circuit` | FF1=LOW, FF2=HIGH | Wiring short, motor failure |
| `Azimuth motor overheating` | FF1=HIGH, FF2=LOW | Prolonged high-current operation |
| `Altitude motor overheating` | FF1=HIGH, FF2=LOW | Prolonged high-current operation |
| `Azimuth motor undervoltage` | FF1=HIGH, FF2=HIGH | Power supply issue |
| `Altitude motor undervoltage` | FF1=HIGH, FF2=HIGH | Power supply issue |

### 8.2 Current Faults

| Fault | Description | Threshold |
|---|---|---|
| `Azimuth motor overcurrent` | Motor drawing too much current | > 5.0 Amps |
| `Altitude motor overcurrent` | Motor drawing too much current | > 5.0 Amps |

The test uses the filtered current (IIR, alpha 0.02 per 10 ms loop, ~0.5 s time constant), only while that axis is moving. The sensor zero is measured at boot (50 samples), re-measured at rest at the start of every homing (64 samples), and tracked slowly once an axis has been idle for 2 s outside a homing.

**Possible causes:**
- Mechanical obstruction
- Binding in gears or drive train
- Motor failure
- Overloaded drive

### 8.3 Stall Faults

| Fault | Description | Detection |
|---|---|---|
| `Azimuth motor stalled` | No encoder pulses while driving | 2 seconds timeout |
| `Altitude motor stalled` | No encoder pulses while driving | 2 seconds timeout |

A stall needs both the time since the drive started and the time since the last accepted pulse to exceed `STALL`, so a stale pulse timestamp from a long idle cannot fault a slew the moment it starts. Every stall test reads the pulse time before the clock (`msSincePulse`). Stalls are checked only while Slewing, never during a homing, where the pulse silence is how a limit switch is found.

**Arrived at limit:** an axis that stalls while driving negative with its count within 2 degrees of its hardware minimum is taken to be at the switch. No fault is raised: the counter is set to the minimum, the target is clamped to it, and `Az limit reached (snap to limit)` or `Alt limit reached (snap to limit)` is printed.

**Possible causes:**
- Motor not turning
- Encoder failure
- Belt/coupling slipped
- Mechanical jam

### 8.4 Position Bounds Faults

| Fault | Description | Detection |
|---|---|---|
| `Azimuth position out of bounds` | Position exceeds physical limits | > 5 deg beyond hardware limit |
| `Altitude position out of bounds` | Position exceeds physical limits | > 5 deg beyond hardware limit |

**Possible causes:**
- Encoder noise adding false pulses
- Mechanical hard stop broken
- Encoder missed pulses accumulating over time
- Motor drove past limit (overcurrent didn't trigger)

This is a sanity check on the counter: if the counted position exceeds what is physically possible, something is wrong and the system stops immediately. It cannot catch a dish that has physically passed 90 degrees in altitude while the counter reads less (section 6.7).

### 8.5 Recovery from Faults

**Option A: RESET, then HOME**

1. Investigate and resolve the fault cause
2. Send `RESET`. The firmware prints `Fault cleared. Use HOME to re-home.` and returns to Ready with the counters unchanged.
3. Send `HOME`. After a stall, a bounds fault or an aborted homing the counters cannot be trusted until it has run.

**Option B: Power cycle**

1. Turn off the controller
2. Investigate and resolve the fault cause
3. Turn on the controller
4. The system will re-home automatically

### 8.6 Homing Faults

| Fault | Printed on the programming port | Cause |
|---|---|---|
| `Homing aborted by STOP - RESET then HOME` | `Homing ABORTED: STOP received - position unknown, RESET then HOME` | `STOP` during a homing |
| `Azimuth motor stalled` / `Altitude motor stalled` | `Homing ABORTED: Az stall during back-off` (or `Alt`) | No pulse for `STALL` while backing off |
| | `Homing ABORTED: no encoder edge leaving the stop` | No edge within 3x `STALL` on the zeroing creep |
| | `Homing ABORTED: Azimuth motor not responding` (or `Altitude`) | No pulse for `STALL` on the drive to `HOMEALT/HOMEAZ` |
| Driver flag or overcurrent | `Homing ABORTED: <fault>` | As sections 8.1 and 8.2 |

---

## 9. Startup and Homing

### 9.1 Startup Sequence

On power-up, the system performs the following sequence:

1. **Initialize hardware**
   - Configure all GPIO pins
   - Enable motor drivers (reset pins HIGH)
   - Set motors to stopped state, DIR positive, pin 26 LOW
   - Attach the encoder interrupts (RISING), set the ADC to 12 bits

2. **Initialize serial ports**
   - Programming port (USB) at 115200 baud
   - Serial1 (pins 18/19) at 115200 baud
   - Native USB bridge to Serial1

3. **Load configuration** from flash, or the `config.h` defaults if flash holds no valid configuration

4. **Measure the current-sensor zero** with the motors off (50 samples, 10 ms apart)

5. **Homing sequence** (section 9.2)

6. **Enter READY state**
   - Output status (section 4.2)
   - Accept commands

**Note:** a homing takes up to about a minute. Skipping the re-approach saves about 40 s.

### 9.2 Homing Sequence

`performHoming()` in `src/main.cpp`. Lines marked (S1) also go to Serial1.

1. **Current zero.** Motors stopped, 500 ms wait, then 64 samples of each sensor are taken as the zero for this homing (S1):
   `Homing: current zero re-measured at rest (shift az <A> A, alt <A> A)`.
   The idle zero tracker does not run during a homing.

2. **First approach** (`driveToLimits`), `Homing: Drive to limits...` (S1).
   - Both axes drive negative with the ramp-up profile.
   - Inside a band of +-5 pulses (+-2.5 degrees, `HOMING_SLOW_APPROACH_PULSES`) of counter zero, each axis stops for 400 ms (`HOMING_SLOW_BRAKE_MS`) and then creeps at `PWM_MIN_SPEED`. Met at full speed, the coast past the current cut scattered the rest over most of a magnet pitch (issue #32).
   - An axis is at its limit when no pulse has passed its debounce for `STALL`. Each stop prints (S1):
     `Homing: Azimuth limit reached at <n> pulses (<deg> deg) [enc: ...] I=<A>A det[armed= creep= cut= low= edges= cutToStall= brake=]`
     and the same for altitude, without `det[...]`.
   - On the first approach `<n>` is a fixed switch-detection offset plus any count drift since the previous homing. The offset is normally −2.0 to +0.5° (most often alt −1.0°, az −0.5°, whether the last homing was an hour or a day ago); only a reading outside that range is drift.
   - A boot homing starts at counter 0 wherever the mount is: it creeps its first 2.5 degrees, then runs at speed.

3. **Azimuth cut edge.** While azimuth creeps, the raw current (8 ADC conversions averaged) is read every pass.
   - The detector arms when the current exceeds 0.3 A (`HOMING_CREEP_CURRENT_A`), taking the driving sign from the creep's opening surge.
   - It books the cut when the **signed** driving-direction current falls below 0.3 A for three consecutive readings, at the counter and time of the first of the three. Signed, because the cut does not take the reading to zero: it flips it, and a reverse transient of 0.5-1 A follows every cut for 150-400 ms.
   - The first counted edge after the cut is the azimuth reference (`azCutEdgePosition`). The cut is repeatable; the 0.3-0.7 degree coast after it is not.
   - More than two edges after the cut means the axis was still driving (S1):
     `Homing: Az <n> edges followed the supposed current cut - not a cut, capture discarded`.

4. **Re-approach, or not.** The first approach reports (S1):
   `Homing: first approach - az cut edge captured|not captured, az arrived creeping|at speed, alt arrived creeping|at speed`.
   - If the cut edge was captured and altitude met its switch at creep, the first approach has done everything a second would (issue #33) (S1):
     `Homing: Re-approach skipped - both axes met the switch at creep and the azimuth cut edge was captured`.
   - Otherwise `Homing: Backing off limits...`. Both counters are set to 0 and both axes drive 5 degrees positive by count. Then the firmware waits until no pulse has arrived for 400 ms (`HOMING_SETTLE_MS`, bounded by `STALL`): the ISR signs a pulse by the DIR pin, so a coast pulse after the reversal would count backwards.
   - Then `Homing: Re-approach limits...` (S1) and a second approach as in steps 2-3.

5. **Zero** (`refineZeroPositiveEdge`). The reed level at rest is read on each axis (5 samples over 50 ms, majority).
   - **Azimuth, cut edge captured:** the counter is set to the pulses coasted past the cut edge (S1):
     `Homing: Az zero on the first edge after the current cut (cut <A>-><A> A, cut->edge <ms> ms, coast <n> pulses beyond it, reed HIGH|LOW at rest)`.
     A HIGH rest keeps that counter. A LOW rest coasted through the cut dwell: the axis creeps positive to the first counted edge, the dwell's entry, and takes the counter there (S1):
     `Homing: Az counter set at the cut dwell's entry (reed LOW at rest, edge after <ms> ms, levels <levels>)`.
   - **Azimuth, no capture:** `Homing: Az no edge followed the current cut - zeroing on the first edge of the creep` (S1). The axis creeps positive and zeroes on the first edge (S1):
     `Homing: Az zero on first edge of the creep (fallback; reed ... at rest, edge after <ms> ms, levels <levels>)`.
   - **Altitude** always creeps positive and zeroes on its first edge (S1):
     `Homing: Alt zero on first edge (reed HIGH|LOW at rest, edge after <ms> ms, levels <levels>)`.
   - Zeroing on a positive-going edge puts the zero on the same edges tracking reads. `<levels>` is the reed's level history during the creep (`L>H@<ms>...`).

6. **Home offset.** `Homing: Moving to home position...`. Each axis drives `HOMEALT`/`HOMEAZ` x 2 pulses positive, and the counters are then set to `HOMEALT`/`HOMEAZ`. Both default to 0, so nothing moves and the mount reads (0, 0) at its zero:
   ```
   Homing complete. Position: Alt=0.0 Az=0.0
   Ready. Type HELP for commands.
   ```

The first-approach counters and the skip are how the controller and scheduler judge a homing: the ESP32 reports `reapproach_skipped`, and the scheduler accepts null second-approach counters on that word alone.

---

## 10. Configuration

### 10.1 Defaults and Flash

`Config cfg` lives in RAM. At boot it is read from flash (DueFlashStorage) and checked against the magic `0x53525431` ("SRT1") and a checksum. The `DEFAULT_*` values in `include/config.h` are used only when that check fails, or after `DEFAULTS`. A configuration saved in flash overrides a changed default in a rebuilt firmware until `DEFAULTS` and `SAVE` are sent. Check `CONFIG` on the mount rather than reading `config.h`.

### 10.2 Settable Defaults

| Define | Value | SET parameter |
|---|---|---|
| `DEFAULT_ALT_HW_MIN` | 0.0 | `ALTHWMIN` |
| `DEFAULT_ALT_HW_MAX` | 90.0 | `ALTHWMAX` |
| `DEFAULT_AZ_HW_MIN` | 0.0 | `AZHWMIN` |
| `DEFAULT_AZ_HW_MAX` | 355.0 | `AZHWMAX` |
| `DEFAULT_ALT_MIN` | 0.0 | `ALTMIN` |
| `DEFAULT_ALT_MAX` | 90.0 | `ALTMAX` |
| `DEFAULT_AZ_MIN` | 2.0 | `AZMIN` |
| `DEFAULT_AZ_MAX` | 353.0 | `AZMAX` |
| `DEFAULT_HOME_ALT` | 0.0 | `HOMEALT` |
| `DEFAULT_HOME_AZ` | 0.0 | `HOMEAZ` |
| `DEFAULT_RAMP_UP_MS` | 500 | `RAMPUP` |
| `DEFAULT_RAMP_DOWN_DEG` | 7.0 | `RAMPDOWN` |
| `DEFAULT_STOP_RAMP_MS` | 300 | `STOPRAMP` |
| `DEFAULT_CURRENT_LIMIT` | 5.0 | `CURRENT` |
| `DEFAULT_STALL_TIMEOUT` | 2000 (`SIM_STALL_TIMEOUT_MS` 200 in simulation) | `STALL` |
| `DEFAULT_DEBOUNCE_MS` | 50 | `DEBOUNCE` |
| `DEFAULT_DEBOUNCE_ALT_MS` | 100 | `DEBOUNCE_ALT` |
| `DEFAULT_BACKLASH_AZ` | 0.0 | `BACKLASH` |

A new tunable needs all five steps: the `#define`, a `Config` field, `loadDefaults()`, `processSetCommand()`, and `showConfig()`/`showHelp()`. A field `loadDefaults()` misses holds garbage until `SAVE`.

### 10.3 Fixed Values (rebuild to change)

In `include/config.h`:

| Define | Value | Meaning |
|---|---|---|
| `PULSES_PER_DEGREE` | 2 | Encoder resolution |
| `SOFTWARE_LIMIT_TOLERANCE` | 4.0 deg | Allowed excursion past a software limit |
| `REVERSAL_SETTLE_MS` | 400 | Pulse silence before DIR flips on a reversal |
| `HOMING_SETTLE_MS` | 400 | Pulse silence after the homing back-off |
| `HOMING_SLOW_APPROACH_PULSES` | 5 | Creep band around the expected zero |
| `HOMING_SLOW_BRAKE_MS` | 400 | Stop before creeping into the switch |
| `HOMING_CREEP_CURRENT_A` | 0.3 | Driving-direction current that separates driving from cut |
| `PWM_STOP` / `PWM_FULL_SPEED` / `PWM_MIN_SPEED` | 255 / 0 / 100 | Inverted PWM |
| `CURRENT_SENSOR_OFFSET_V` / `CURRENT_SENSOR_SENSITIVITY` | 1.65 V / 0.044 V/A | Sensor nominal zero and scale |
| `STATUS_INTERVAL_MS` | 1000 | Unsolicited Serial1 status period |
| `MAIN_LOOP_DELAY_MS` | 10 | Main loop period |
| `ENABLE_SERIAL1` | 1 | Set to 0 to disable Serial1 |

In `src/main.cpp`: `FAULT_FLAG_PERSIST_COUNT` 5, `POSITION_BOUNDS_TOLERANCE` 5.0 deg, `PULSE_MIN_WIDTH_US` 1000, `OFFSET_TRACK_IDLE_LOOPS` 200 (2 s), `CURRENT_FILTER_ALPHA` 0.02.

After changing any of these, rebuild and upload:

```bash
pio run -e due --target upload
```

---

## 11. Simulation Mode

Simulation mode allows you to test the full control system - state machine, motion profiles, serial commands, homing sequence, position tracking, and safety logic - without any drive hardware connected. It is enabled at compile time via the `simulation` PlatformIO environment.

### 11.1 How It Works

When built with `-DSIMULATION_MODE`, the firmware replaces the motor, encoder and fault-flag I/O with software stubs using preprocessor macros. The core control logic (state machine, motion profiles, serial commands) runs unmodified - only the lowest-level hardware interface is swapped out.

#### Position Feedback (Pulse Simulation)

On real hardware, reed switch encoders generate interrupt-driven pulses as the motors turn (2 pulses per degree, RISING edge). The ISRs read the motor direction pin to determine whether to increment or decrement the position counter.

In simulation mode, a `simulatePulses()` function replaces the interrupt-driven feedback. It runs every loop iteration (10ms) and:

1. Reads the **shadow PWM value** to determine motor speed. The PWM uses inverted logic (255 = stopped, 0 = full speed), so the speed fraction is calculated as:

   ```
   speed = (255 - pwm) / 255
   ```

2. Reads the **shadow direction state** to determine whether to increment or decrement position.

3. **Accumulates fractional pulses** over real elapsed time using the configured maximum speed (`SIM_MAX_SPEED_DEG_S`, default 180 deg/s):

   ```
   pulses_this_tick = speed * max_pulse_rate * dt
   ```

   A floating-point accumulator tracks sub-pulse fractions. When the accumulator reaches 1.0, a whole pulse is generated and the position counter is updated, exactly as the real ISR would.

4. **Updates the `lastPulse` timestamp** with each generated pulse, which keeps the stall detection logic happy (no false stall faults while the simulated motor is running).

5. **Simulates physical hard stops** at the configured **hardware** limits (`cfg.azHwMin`, `cfg.azHwMax`, `cfg.altHwMin`, `cfg.altHwMax`). When the simulated position reaches a limit, pulse generation stops. This naturally causes the stall detection timeout to fire - exactly as a real motor stalling against a limit switch would. This is what makes the homing sequence work in simulation: the motors "drive" toward the limits, "stall" when they arrive, and the homing logic detects it normally.

The `simulatePulses()` function is called from every loop that drives a motor, nine places in all:
- The main `loop()`, after `updateMotion()`
- `driveToLimits()` (both approaches)
- `backOffFromLimits()`: the drive and the settle wait
- `refineZeroPositiveEdge()`
- The home-offset loop in `performHoming()`
- The three creep loops of `probeAzSwitch()` (`PROBE`)

#### Current Sensing

The current sensors (44mV/A, bipolar) are read via the Due's 12-bit ADC (3.3V reference). In simulation mode, the current sensor pins (A0, A1) read real hardware — only motor control, encoder, and fault flag I/O is simulated. This allows testing the current sensing and calibration with real sensors while the motor control loop runs in simulation.

With no motor current the azimuth cut detector does not arm, so a simulated homing takes the re-approach and the fallback creep zero. The cut-edge capture and the re-approach skip are not exercised.

#### Fault Flag Pins

The motor driver fault flags (FF1/FF2 for each axis) are read via `digitalRead()`. In simulation mode, `digitalRead()` returns `LOW` for the four fault-flag pins; since both flags LOW indicates normal operation, no driver faults will be detected. Other pins, the encoder pins included, are read from the hardware, so the reed-level reads in homing (`reedRestsHigh`) and in the end-of-slew finish see whatever the bench pins show.

#### GPIO and Interrupts

`attachInterrupt()` becomes a no-op. `pinMode()` is a no-op for the motor, encoder, fault-flag and driver-reset pins and real for all others. Motor control writes (`analogWrite` for PWM, `digitalWrite` for direction) are intercepted and stored in shadow variables; other `digitalWrite` calls (driver reset, calibrator) reach the pins. `analogReadResolution()` is not overridden: the current sensors need the real 12-bit ADC.

### 11.2 Simulation Parameters

These are defined in `include/config.h` under the `SIMULATION_MODE` guard:

| Parameter | Default | Description |
|---|---|---|
| `SIM_MAX_SPEED_DEG_S` | 180.0 | Maximum simulated motor speed in degrees/second at full PWM |
| `SIM_INITIAL_AZ_DEG` | 20.0 | Simulated starting azimuth before homing (degrees) |
| `SIM_INITIAL_ALT_DEG` | 10.0 | Simulated starting altitude before homing (degrees) |
| `SIM_STALL_TIMEOUT_MS` | 200 | Stall timeout loaded by `loadDefaults()` in simulation |

The initial position values set how far the simulated telescope must drive during homing before it reaches the limits. The defaults sit close to the limits so a simulated homing is short; larger values give a longer homing test. A configuration saved to flash by a hardware build carries its own `STALL` (2000 ms) into a simulation build until `DEFAULTS`.

### 11.3 What Is Tested vs. What Is Not

| Tested in simulation | Not tested |
|---|---|
| State machine transitions (INIT, HOMING, IDLE, DRIVING, FAULT) | Real EMI/noise on reed switch signals |
| Motion profiles (acceleration, cruise, deceleration, reversal) | Actual motor driver behaviour |
| Homing sequence (limit detection, back-off, re-approach, creep zero) | Current-cut detection, cut-edge zero, re-approach skip |
| Serial command parsing and dispatch | Real current draw and inrush |
| Position limit enforcement | Mechanical stall characteristics |
| Stall detection logic (triggers naturally at simulated limits) | Interrupt timing edge cases |
| Configuration management (SET/SAVE/LOAD/DEFAULTS) | Motor driver fault flag hardware, flash storage wear |

### 11.4 Example Session

```
=================================
SRT Motor Driver v1.2
Acre Road Observatory, Glasgow
*** SIMULATION MODE ***
ESP32 Bridge: Native USB <-> Serial1
=================================

Type HELP for commands.

Calibrating current sensors...
  Az offset: <V>V
  Alt offset: <V>V
Starting homing sequence...
Homing: current zero re-measured at rest (shift az <A> A, alt <A> A)
Homing: Drive to limits...
...
Homing: Az zero on first edge of the creep (fallback; ...)
Homing: Alt zero on first edge (...)
Homing: Moving to home position...

Homing complete. Position: Alt=0.0 Az=0.0
Ready. Type HELP for commands.

Alt:0.0 Az:0.0 Ialt:0.0A Iaz:0.0A Status:Ready *45
> 45 270
Slewing to Alt:45.0 Az:270.0
Alt:0.5 Az:0.5 Ialt:0.0A Iaz:0.0A Status:Slewing -> Alt:45.0 Az:270.0 *26
Alt:1.0 Az:1.0 Ialt:0.0A Iaz:0.0A Status:Slewing -> Alt:45.0 Az:270.0 *26
...
Alt:45.0 Az:270.0 Ialt:0.0A Iaz:0.0A Status:Ready *71
```

---

## 12. Troubleshooting

### 12.1 System Does Not Start

| Symptom | Check |
|---|---|
| No serial output | USB cable, correct port selected |
| Stuck in homing | Motor connections, encoder connections. `STATUS` is answered during a homing; `STOP` aborts it (then `RESET`, `HOME`). |
| Immediate fault | Motor driver power, fault flag wiring |

### 12.2 Motors Do Not Move

| Symptom | Check |
|---|---|
| PWM output but no motion | Motor driver reset pins (should be HIGH) |
| No PWM output | PWM pin connections (pins 8, 10) |
| Motors run backwards | Direction pin wiring (pins 9, 11), `AZ_DIR_INVERT` / `ALT_DIR_INVERT` |

### 12.3 Position Errors

| Symptom | Check |
|---|---|
| Wrong position after homing | The homing lines (section 9.2): first-approach counter, `cut`/`edges` in `det[...]`, reed level at rest. `HOMEALT`/`HOMEAZ` should be 0. |
| Position drifts | Encoder debounce (`DEBOUNCE`, `DEBOUNCE_ALT`): read the `[enc: ...]` statistics on the homing limit lines before changing either |
| Overshoots target | `RAMPDOWN` (increase value) |
| Jerky motion | `RAMPUP` (increase value) |

### 12.4 False Overcurrent Faults

| Symptom | Check |
|---|---|
| Faults with low actual current | Sensor zero: measured at boot and at each homing (`Homing: current zero re-measured at rest (shift ...)`); `XTRACE` shows the raw readings against a frozen zero |
| Faults only at startup | Motor inrush; the limit is tested on the filtered current |

### 12.5 Serial Communication Issues

| Symptom | Check |
|---|---|
| No response to commands | Line ending settings (need CR or LF) |
| Garbled output | Baud rate (must be 115200) |
| ESP32 not receiving | TX/RX swapped (Due 18 -> IO14, Due 19 <- IO4), common ground |
| Controller reports drive targets lost | `ERR UNKNOWN` / `ERR DRIVE` replies and the controller's `drive_ack` counts (section 4.3) |

---

## Appendix A: Quick Reference

### Commands

| Command | Example | Description |
|---|---|---|
| Go to position | `45 180` or `DRIVE 45 180` | Move to Alt=45, Az=180 |
| Home | `HOME` | Run the homing sequence |
| Stop | `STOP` | Stop both motors; aborts a homing |
| Reset | `RESET` | Clear a fault (does not re-home) |
| Status | `STATUS` | Print the status line |
| Configuration | `CONFIG`, `SET <p> <v>`, `SAVE`, `LOAD`, `DEFAULTS` | Section 6.3 |
| Diagnostics | `XTRACE [s]`, `PROBE [n]`, `TEST2`, `TEST2H` | Section 6.4 |

### Status Output

```
Alt:<deg> Az:<deg> Ialt:<A>A Iaz:<A>A Status:<state> [<fault>] [-> Alt:<deg> Az:<deg>] *HH
```

### Serial1 Replies

```
ACK DRIVE <alt> <az>
ERR DRIVE fault|homing|limits
ERR UNKNOWN <line>
Homing: busy - ignored '<line>'
```

### Pin Summary

```
Motor Control:  8(PWM-Az), 9(DIR-Az), 10(PWM-Alt), 11(DIR-Alt)
Driver Reset:   22(Az), 24(Alt)
Encoders:       12(Az), 13(Alt)
Fault Flags:    4,5(Az), 6,7(Alt)
Current Sense:  A0(Alt), A1(Az)
Serial1:        18(TX), 19(RX)
Calibrator:     26 (active HIGH, drives nothing)
```

---

*Document revision: 1.2*
*Updated: September 2026*

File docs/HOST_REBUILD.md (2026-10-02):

# Rebuilding the observatory computer

This document takes a blank replacement machine to a working Acre Road SRT workstation. It is written for whoever does it, very likely an agent such as Claude, and so it gives exact paths, versions and commands. Where something is already documented elsewhere, this document points to it instead of repeating it.

**Last checked against the running machine: 2026-09-30** (host `ettus3`).

**Keep it current.** Any change to the host goes in here in the same commit: a package, a udev rule, a service, a path, a group, a cron job, a file outside git that the telescope depends on. The environment snapshots in `docs/host/` are regenerated with the commands in §11. A rebuild that fails because this document is stale is this document's fault.

---

## 1. The machine as it is

| | |
|---|---|
| Hostname | `ettus3` |
| OS | Ubuntu 24.04.4 LTS (Noble), kernel 7.0 generic |
| CPU / RAM / disk | Intel i7-4790, 8 threads; 8 GB RAM; 1.8 TB (`/dev/sda2`, 5 % used) |
| User | `astro` (uid 1000). Groups: `adm dialout cdrom sudo dip video plugdev users lpadmin` |
| Repository | `/home/astro/21-cm-radio-telescope-v2`, cloned from `https://github.com/acrerd/21-cm-radio-telescope-v2.git` |
| Python (observing) | radioconda at `/home/astro/radioconda`: Python 3.12.9, GNU Radio 3.10.12.0, UHD 4.8.0 |
| Python (timing) | conda env `pint`: PINT 1.1.7, Python 3.11 |
| Python (PRESTO) | conda env `presto` (conda-forge `presto-pulsar`), plus a patched `prepfold` in `/home/astro/opt/presto-acre/bin/` |
| Firmware toolchain | PlatformIO at `~/.platformio/penv` |
| Time | `systemd-timesyncd` (NTP, ntp.ubuntu.com). No chrony |

**Paths are hard-coded.** `/home/astro/...` appears throughout: the launch scripts, `receiver_python_path`, `PINT_PY`, `PRESTO_BIN`, `PREPFOLD_ACRE`, and Claude's memory path. Keep the user `astro` and these locations. Moving them means editing all of those.

**Memory is tight.** 8 GB was enough once the pulsar fold was made to stream (§6 of `docs/PULSAR_PROCESSING.tex`). A replacement should have 16 GB or more.

---

## 2. What plugs into it

| Connection | Where | Notes |
|---|---|---|
| USRP **B200** (one RX channel, AD9364) | a **USB 3** port | `lsusb` calls it "USRP B210": the USB ID 2500:0020 is shared by both models. UHD says `Detected Device: B200`. It must be on USB 3 (5000M in `lsusb -t`). |
| B200 RX2 | the receive chain: feed → SAWbird+ H1 → cable | |
| B200 TX/RX | 30 dB pad → the vertex dipole | the pilot and the test transmitter; off by default |
| B200 REF IN | Thunderbolt GPSDO **10 MHz** | selected and checked by `select_clock_source` through the `ref_locked` sensor |
| B200 PPS IN | Thunderbolt **1 PPS** | in use: the 2026-09-28 pulsar run recorded `time_source` pps. The input takes 1.8–5 V, so the Thunderbolt's TTL is fine. Picked up automatically (`H1_TIME_SOURCE=auto`). |
| Thunderbolt serial (DB9) | USB, through an **RS-232** adapter (FTDI FT232R, serial `A9DZ2ZSW`) | **connected 2026-09-30**, decoded first time: locked, 8 satellites, osc ±0.14 ppb, PPS ~1 ns, DAC 2.111 V, 43.5 °C. TSIP at 9600 8-N-1, read by `thunderbolt.py`. Until the udev rule of §7 exists, `scheduler_config.json` sets `thunderbolt_device` to `/dev/serial/by-id/usb-FTDI_FT232R_USB_UART_A9DZ2ZSW-if00-port0`. Unit settings (in its EEPROM, not on this computer): loop time constant **100 s**, damping 1.0; **cable-delay compensation −50.5 ns** (PPS offset, negative advances: 10 m of RG-58 at velocity factor 0.66 to a Leo Bodnar **LBE-1304-10-BX1** antenna; the antenna's own delay is not included); **surveyed antenna position 55.9025269, −4.3074782, 108.75 m above the WGS-84 ellipsoid** (self-survey of 2000 fixes, 2026-09-30, 3.05 m east and 1.8 m below the previous stored position; 26.6 m from the dish at bearing 65°). All set 2026-09-30 through the scheduler (`/api/clock/survey`, `/api/clock/cable-delay`); read them with the monitor or TSIP 0x8E-A8 / 0x8E-4A, and set a replacement unit the same. RS-232 levels: a 3.3 V TTL adapter will not read it. **Plugging it in reset the B200** (it dropped off USB 4 s later and the running receiver aborted): plug USB devices in between observations. |
| Controller (WT32-ETH01) | the second network card, TP-Link TG-3468 (`enp5s0`, `r8169`) | a private link: see `docs/OBSERVATORY_HOST_SETUP.md` |
| Campus network | the motherboard network card | internet, NTP, GitHub, remote access |
| Safety camera | USB (`/dev/video0`) | needs the `video` group (§7) |

---

## 3. Order of work

1. Install the OS and create the user (§4).
2. Build the controller link (§5, by following `docs/OBSERVATORY_HOST_SETUP.md`).
3. Install radioconda and its additions (§6).
4. Set up UHD: the udev rule and the FPGA images (§7).
5. Clone the repository, authenticate git, **restore the files git does not hold** (§8).
6. Create the PINT and PRESTO environments and build the patched prepfold (§9).
7. Install PlatformIO (only needed for firmware work) (§10).
8. Set up the launchers, remote access and Claude's memory (§10).
9. Run the whole check (§12).

---

## 4. OS and user

```
# Ubuntu 24.04 LTS desktop, user astro (uid 1000)
sudo apt update && sudo apt install -y git gh curl wmctrl openssh-server network-manager \
     pipewire wireplumber gstreamer1.0-tools gstreamer1.0-plugins-good \
     avahi-daemon waypipe gjs
# gstreamer1.0-*: v4l2src, jpegenc - the camera stream
# avahi-daemon: srt-controller.local, the scheduler's fallback name for the controller
# waypipe: the one graphical path (the manual receiver GUI) over ssh, OBSERVATORY_HOST_SETUP §10
# gjs: runs the operator page's JavaScript headless - the check before calling a page change done (CLAUDE.md)
sudo usermod -aG video,dialout,plugdev astro      # camera, serial, USB
# log out and back in: a new group reaches only processes started from a new login
```

- **Desktop applications the launcher opens:** Firefox (the snap). Stellarium is installed but started by hand (§10).
- **ssh:** the observatory is normally worked over ssh. Copy `~/.ssh/authorized_keys` from the old machine, or add keys afresh; see `docs/SSH_ACCESS.txt`.

---

## 5. The controller link

Follow `docs/OBSERVATORY_HOST_SETUP.md` in full: the second card, the NetworkManager connection `srt-link` (`ipv4.method shared`, host 192.168.50.1/24), the controller's address pinned by MAC in `/etc/NetworkManager/dnsmasq-shared.d/srt.conf`, the firewall, and the checks. The controller keeps its own settings and its pointing model in its own flash, so nothing on the controller changes when the host is replaced.

---

## 6. radioconda (the observing Python)

1. Install **radioconda 2025.03.14** (linux-64) to `/home/astro/radioconda` with its installer from https://github.com/ryanvolz/radioconda/releases. A newer release is fine only if GNU Radio 3.10 and UHD 4.x remain. Then rerun the test suite, because behaviour has been verified on GNU Radio 3.10.12 and UHD 4.8.0. One specific: through `integrate_ff`, GNU Radio 3.10.12 rounds a tag's offset to the nearest output item, and `_TagTap` relies on reading tags before that block.
2. Add what was installed by hand after the installer, with pip into radioconda:
   ```
   /home/astro/radioconda/bin/python -m pip install astropy==8.0.1 pytest==9.1.1 esprima ipykernel psutil
   ```
   - `astropy` brings `pyerfa` and `astropy-iers-data`.
   - `esprima` is used by `tests/test_page_structure.py` to parse the page's JavaScript.
   - `ipykernel` is for the notebooks.
3. The full package list at the time of writing is `docs/host/radioconda-base-packages.txt` (conda) and `docs/host/radioconda-pip-freeze.txt` (pip). Use them to find anything missing.

Do not install anything else into radioconda: PINT and PRESTO have their own environments (§9). The scheduler re-executes itself under `/home/astro/radioconda/bin/python`.

---

## 7. UHD: USB permissions and firmware images

```
sudo cp /home/astro/radioconda/lib/uhd/utils/uhd-usrp.rules /etc/udev/rules.d/
sudo udevadm control --reload-rules && sudo udevadm trigger
/home/astro/radioconda/bin/uhd_images_downloader -t b2xx     # into radioconda/share/uhd/images
/home/astro/radioconda/bin/uhd_find_devices                   # must list the B200
```

- The images needed are `usrp_b200_fw.hex` and `usrp_b200_fpga.bin`. The current machine has the full set in `/home/astro/radioconda/share/uhd/images/`.
- If the rule file is somewhere else in the radioconda tree, find it with `find /home/astro/radioconda -name uhd-usrp.rules`.

**Thunderbolt serial adapter** (connected 2026-09-30, serial `A9DZ2ZSW`; the rule below is not yet installed - it needs sudo - so the config uses the by-id path instead). A fixed name, so the scheduler's `thunderbolt_device` (`/dev/thunderbolt`) survives other USB-serial devices appearing first. Fill in the adapter's own serial number from `udevadm info -a -n /dev/ttyUSB0 | grep '{serial}'`; the vendor and product are FTDI's FT232R.

```
sudo tee /etc/udev/rules.d/99-thunderbolt.rules <<'RULE'
SUBSYSTEM=="tty", ATTRS{idVendor}=="0403", ATTRS{idProduct}=="6001", ATTRS{serial}=="A9DZ2ZSW", SYMLINK+="thunderbolt", GROUP="dialout", MODE="0660"
RULE
sudo udevadm control --reload-rules && sudo udevadm trigger
ls -l /dev/thunderbolt                                        # -> ttyUSBn
/home/astro/radioconda/bin/python receiver_scheduler/thunderbolt.py /dev/thunderbolt --seconds 5
```

The last line should print an `AB` and an `AC` line each second. Run it **only with the scheduler stopped**: the scheduler's monitor is the port's one reader, and a second process on the port splits the TSIP replies between them (it did on 2026-09-30, and the monitor decoded a garbled reply as "loop 0 s"). With the scheduler running, read the unit through `/api/clock` instead. `astro` needs the `dialout` group (§4). No scheduler restart is needed: it looks for the device every 30 s. Until this rule is installed, `thunderbolt_device` in `scheduler_config.json` names the adapter by its `/dev/serial/by-id/usb-FTDI_FT232R_USB_UART_A9DZ2ZSW-if00-port0` path; change it to `/dev/thunderbolt` afterwards (a changed value reaches the running monitor without a restart).

**Camera.** The camera needs the scheduler process itself to hold the `video` group. A scheduler started from a shell that predates `usermod` lacks it until the next login. The launch line used from such a shell is `setsid nohup sg video -c "bash start_scheduler.sh"`, and after a fresh login a plain start is enough. Check with `grep Groups /proc/<scheduler pid>/status`, which must list 44.

---

## 8. The repository, and the files git does not hold

```
cd /home/astro && git clone https://github.com/acrerd/21-cm-radio-telescope-v2.git
gh auth login          # GitHub, HTTPS, "Login with a web browser" or a token
gh auth setup-git      # git then uses gh's token over HTTPS
```

In git already: the code, the calibrations in force (`gain_calibration.json`, `bandpass_template*.json`, `beam_calibration.json` and `beam_calibrations/`, `horizon_profiles/`, `pointing_data*.json`, `scallop_reference.json`), the pulsar timing products (`receiver_scheduler/pulsar_timing/`) and templates, and the Thunderbolt's long-term log (`receiver_scheduler/reference_log/`, one row of statistics every 10 min, committed with the rest).

**Not in git: copy these from the old machine or its backup.** `receiver_scheduler/` is abbreviated `rs/` below.

| File | What it is | If lost |
|---|---|---|
| `rs/scheduler_config.json` | the live configuration: controller URL; the pulsar band (`pulsar_sample_rate_hz` 32e6, `pulsar_lo_hz` 1413e6); the two monitors (`sun_monitor` on; `pulsar_monitor` on, `pulsar_monitor_window` follow, `_start` 20:00, `_hours` 16); `thunderbolt_device` and `thunderbolt_baud` (9600); `receiver_pilot_enabled: false` (with `receiver_pilot_tx_gain_db: 70` left set from the wired test of 09-22); banner; any `receiver_*` instrument overrides (none set) | the scheduler starts on code defaults: both monitors off, no Thunderbolt read. **Check the pilot and instrument keys** before observing. |
| `rs/h1_schedule.json` | the bookings | future bookings are gone |
| `rs/pointing_model.json` | the scheduler's copy of the model in force, used by the scallop reduction and drift parking | the controller still holds the model and `/pointing` serves it; files fall back to the model embedded in each recording |
| `rs/last_observation.json` | pointer to the last run | cosmetic |
| `rs/data/` (about 3 GB now) | every recording (`data/observations/`), `solar_reference_history.json`, PRESTO exports, diagnostics | recordings are "archived on the sky", but a year of them is not re-observable in practice. **Copy it.** |
| `rs/data/controller_firmware/` | the ELF of each controller build flashed (`current.elf` is the one running; the others are named by UTC time and commit), from `esp32_controller_arduino/.pio/build/wt32-eth01-ota/firmware.elf` at each flash | a panic's backtrace (`/diag`, logged by the scheduler's watchdog) can only be decoded against the exact build that was running. After a rebuild, re-flash and copy the new ELF to `current.elf` |
| `rs/scheduler.log*` | the operational record | history only |
| `~/.claude/projects/-home-astro-21-cm-radio-telescope-v2/memory/` | Claude's working memory for this project | Claude loses the lessons learned. Copy the folder to the same path. |
| `~/.config/gh/hosts.yml` | the GitHub token | re-run `gh auth login` rather than copy a token |
| `/etc/NetworkManager/...`, `/etc/udev/rules.d/uhd-usrp.rules` | system configuration | rebuilt by §5 and §7 |

---

## 9. Timing and PRESTO environments

```
C=/home/astro/radioconda/bin/conda
$C env create -f /home/astro/21-cm-radio-telescope-v2/docs/host/env-pint.yml     # PINT 1.1.7, Python 3.11
$C env create -f /home/astro/21-cm-radio-telescope-v2/docs/host/env-presto.yml   # presto-pulsar and build tools
```

The exact package lists at the time of writing are `docs/host/env-pint-packages.txt` and `docs/host/env-presto-packages.txt`.

**PINT** needs the JPL ephemeris DE421 on first use and fetches it itself into `~/.cache/astropy`, so it needs internet once. `pulsar_toa.py` calls PINT at `/home/astro/radioconda/envs/pint/bin/python` (`PINT_PY`).

**Patched prepfold**, so that PRESTO knows the site. Instructions are at the top of `tools/presto_acre_road.patch`:

```
mkdir -p /home/astro/src && cd /home/astro/src
git clone https://github.com/scottransom/presto.git && cd presto
git checkout 06083ad                                  # the commit it was built from on 2026-09-25
git apply /home/astro/21-cm-radio-telescope-v2/tools/presto_acre_road.patch
# in the presto env:
meson setup build-acre --prefix=/home/astro/opt/presto-acre && meson compile -C build-acre prepfold
mkdir -p /home/astro/opt/presto-acre/bin
cp build-acre/src/prepfold build-acre/src/libpresto.so /home/astro/opt/presto-acre/bin/
```

`libpresto.so` must sit next to `prepfold`, because its rpath puts `$ORIGIN` first. If the patched binary is missing, `pulsar_fold.prepfold_path()` falls back to the stock one, which folds the same but calls the site "Unknown".

---

## 10. Launchers, firmware tools, remote access, Claude

- **Desktop launcher:** `~/Desktop/Start SRT Sofware.desktop` (the spelling is as found) runs `receiver_scheduler/start_srt_software.sh`. That starts the scheduler (below) and opens Firefox on the controller. VS Code and Stellarium were taken out of it on 2026-10-01 at the operator's request.
  ```
  [Desktop Entry]
  Type=Application
  Name=Start SRT Sofware
  Exec=/home/astro/21-cm-radio-telescope-v2/receiver_scheduler/start_srt_software.sh
  Path=/home/astro/21-cm-radio-telescope-v2
  Terminal=false
  Icon=applications-science
  ```
- **The scheduler:** the launcher runs `receiver_scheduler/start_scheduler.sh` detached (`setsid`, console output in `/tmp/srt-scheduler-console.log`); the VS Code workspace `receiver_scheduler/SRT Software.code-workspace` still runs the same script on folder-open if it is opened by hand. It starts `h1_web_scheduler.py` on 127.0.0.1:5000 only if one is not already running. To restart it over ssh: check `/api/status` is idle, `kill` the scheduler's PID, then `setsid nohup receiver_scheduler/start_scheduler.sh > /tmp/srt-scheduler-console.log 2>&1 < /dev/null &`. A restart clears the monitors' hold-off and the Thunderbolt's in-memory history.
- **Stellarium** (by hand, not from the launcher): `~/.stellarium/modules/TelescopeControl/telescopes.json` holds the telescope, `"host_name": "192.168.50.120"`, `"tcp_port": 10001`, `"connection": "remote"`, `"equinox": "J2000"`, `"connect_at_startup": true`. Until 2026-10-01 it still named the pre-link address 192.168.106.120 and tried to connect there over the campus network. A goto from Stellarium reaches the controller without the scheduler seeing it.
  - It is **deliberately not a systemd service**, and must not come up unattended.
  - It binds to loopback on purpose: it has no authentication.
- **PlatformIO** (only for ESP32 or Due firmware): `python3 -m venv ~/.platformio/penv && ~/.platformio/penv/bin/pip install platformio`. Builds per CLAUDE.md, using `~/.platformio/penv/bin/pio`.
- **Remote access:** ssh with port forwarding for the web UIs, and waypipe for applications. See `docs/SSH_ACCESS.txt`, `docs/ettus3-tunnel.bat` and `docs/OBSERVATORY_HOST_SETUP.md` §10. A new host key means updating `known_hosts` on the remote machines.
- **Claude:** install Claude Code. Copy the project memory folder (§8). `CLAUDE.md` in the repository carries the rest.

---

## 11. Refreshing the snapshots in `docs/host/`

Run after any change to an environment, and commit the result with the change:

```
C=/home/astro/radioconda/bin/conda; D=/home/astro/21-cm-radio-telescope-v2/docs/host
$C list -n base --export > $D/radioconda-base-packages.txt
/home/astro/radioconda/bin/python -m pip list --format=freeze > $D/radioconda-pip-freeze.txt
$C env export -n pint   --from-history | grep -v '^prefix:' > $D/env-pint.yml
$C env export -n presto --from-history | grep -v '^prefix:' > $D/env-presto.yml
$C list -n pint --export > $D/env-pint-packages.txt; $C list -n presto --export > $D/env-presto-packages.txt
```

---

## 12. Checking the rebuilt machine

Do these in order; each depends on the ones before.

1. `uhd_find_devices` lists a **B200**. `lsusb -t` shows it at 5000M.
2. A 60 s spectral recording with the mount parked:
   ```
   H1_OUTPUT_FILE=/tmp/check.h5 timeout -s INT 60 /home/astro/radioconda/bin/python receiver_scheduler/b210_h1_receiver.py --headless --sdr b210
   ```
   The log must say `Clock: EXTERNAL 10 MHz reference, locked`, and the file's `overflows` must sum to 0.
3. The controller: `curl http://192.168.50.120/status` answers. Check its NTP sync as `docs/OBSERVATORY_HOST_SETUP.md` §8 describes.
4. The scheduler: start it from the desktop launcher, then check that `curl http://127.0.0.1:5000/api/status` answers and the page loads.
5. The camera: `curl -o /tmp/s.jpg -w '%{http_code}' http://127.0.0.1:5000/api/camera/snapshot` returns 200. The snapshot alone does not prove the live view, since it falls back to a one-shot read of the device: `curl -s -m 5 'http://127.0.0.1:5000/api/camera/stream?fps=5' | grep -a -c srt-camera` should count frames, and must do so with nobody logged in at the console.
6. The tests: `cd receiver_scheduler && /home/astro/radioconda/bin/python -m pytest`.
   - About 700 should pass.
   - `TestFlaskAPI::test_post_config` fails on the observatory host by design, because it reaches the live controller.
   - **Run the tests only while nothing is recording.**
   - `tests/test_pulsar_toa.py::test_pint_agrees_with_our_phase_and_reads_our_tim` exercises the PINT environment and our site registration.
7. PRESTO: on the Observe tab, select a pulsar recording and press **PRESTO fold**. The plot must name the telescope "Acre Road SRT", which proves the patched binary is in use.
8. The whole chain: book a short tracked spectrum, let it run, and plot it.

---

## 13. Worth doing while the old machine still exists

- Copy §8's list to the new machine, then compare checksums of `data/observations/`.
- Keep the old disk untouched until the new machine has observed and plotted a full night.
- There is no scheduled backup of §8's files today. A nightly copy of `receiver_scheduler/data/` and the untracked JSON files to other storage would make a hardware failure an inconvenience rather than a loss.

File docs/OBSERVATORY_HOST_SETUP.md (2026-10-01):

# Observatory Host Setup

**Status:** Implemented (first built 2026-08-19, issue #10)
**Purpose:** Build an observatory computer that owns a private Ethernet link to the SRT controller

---

## 1. What this builds and why

The observatory computer is given a **second Ethernet card**. The controller
(WT32-ETH01) hangs off it on a private point-to-point link that this host owns
completely: it serves the address, resolves names, and routes the link out to the
internet.

The first card stays on the site LAN and is how people reach the computer.

```
   site LAN ──── eno1 ┐
                      │  observatory computer     (NAT + DHCP + DNS)
  controller ─── enp5s0 ┘  192.168.50.1/24
  192.168.50.120
```

**Why bother.** On the site LAN the controller had whatever address the site
handed it, and that address was hard-coded in seven places in the code and
twenty-five in the documentation. Every renumbering was a code change. On a
private link the address is permanently ours.

**No firmware change is needed.** The controller stays on DHCP; its address is
pinned by MAC on the host. Nothing on the controller is configured for this link,
so the whole arrangement reverses by moving one cable back to the site switch.
That reversibility is the point — keep it.

**The one thing the link breaks is time**, and it matters more than it sounds.
The controller syncs its clock from the internet, and pointing is computed from
sidereal time, so a link with no route out mispoints the telescope overnight in a
way that is tedious to diagnose after the fact. Step 4 routes it; step 8 proves
it. Do not skip either.

### Address plan

Must avoid the site LAN, `192.168.4.0/24` (the controller's own WiFi AP), and
`192.168.1.0/24` (common home-router range, and the firmware's old placeholder).
`192.168.50.0/24` is used here; nothing depends on the numbers, but if you change
them, change `DEFAULT_ETH_*` in `esp32_controller_arduino/src/config.h` too.

| Host | Address |
|---|---|
| Observatory computer, second card | `192.168.50.1` |
| Controller | `192.168.50.120` |

---

## 2. Prerequisites

- Ubuntu 24.04 with **NetworkManager** managing the interfaces (this guide was
  written against NM 1.46). If the host uses `systemd-networkd` or plain netplan
  without NM, the `nmcli` steps need translating.
- A free PCIe slot.
- `radioconda` at `/home/astro/radioconda` for the scheduler and receiver.
- PlatformIO at `/home/astro/.platformio/penv/bin/pio` for firmware builds.
- The repository cloned at `/home/astro/21-cm-radio-telescope-v2`.

Confirm NetworkManager is in charge before going further:

```bash
nmcli device status        # the site interface should show a connection name
```

---

## 3. Fit the second card

**TP-Link TG-3468** (~£10). PCIe x1, Realtek RTL8168, driven by the in-kernel
`r8169` module, so Ubuntu brings it up with no driver install. Ships with both
full-height and low-profile brackets.

> **Avoid cheap "Intel I210" listings.** A genuine i210-T1 is the better card in
> the abstract, but real ones are £35-45 from a trade supplier and the £15-20
> marketplace listings are a well-documented counterfeit market. Counterfeits
> frequently carry cloned or duplicated MAC addresses — exactly the failure this
> design depends on *not* happening, since the controller's address is pinned by
> MAC. The link carries a status poll and a coordinate stream, and the
> controller's PHY is 100BASE-TX anyway: buy on driver reliability, not speed.

Shut down, unplug from the mains, fit the card, boot.

```bash
ip -br link                       # a new interface appears, e.g. enp5s0
lspci -k | grep -A3 -i ethernet   # confirm "Kernel driver in use: r8169"
```

Note the interface name — every step below needs it. It comes from the card's bus
position, so unlike a USB adapter it is stable across reboots and does not depend
on the MAC.

If nothing new appears, check `lspci | grep -i ethernet` to see whether the card
is on the bus at all.

---

## 4. Build the link

Do this while the controller is **still on the site switch**. Nothing is at risk
here; the controller stays reachable throughout.

Substitute your interface name for `enp5s0` and the controller's MAC for the one
below — read it from the controller's web UI (`/wifi/status` → `eth_mac`) or from
the site switch's table.

```bash
sudo nmcli connection add type ethernet \
    con-name srt-link \
    ifname enp5s0 \
    ipv4.method shared \
    ipv4.addresses 192.168.50.1/24 \
    ipv4.never-default yes \
    ipv6.method ignore
```

- **`ipv4.method shared` is the important one.** It sets the address, enables IP
  forwarding, installs the NAT rules so the controller can reach the internet,
  and runs a dnsmasq on the interface providing DHCP and a DNS forwarder. All
  four in one setting.
- **`ipv4.never-default yes`** stops the host routing general traffic down a link
  with only a microcontroller on the far end.
- **`ipv6.method ignore`** — nothing here speaks IPv6.

Pin the controller's address by MAC so it can stay on DHCP:

```bash
sudo tee /etc/NetworkManager/dnsmasq-shared.d/srt.conf >/dev/null <<'EOF'
# Controller stays on DHCP; the address is pinned here so the whole
# arrangement is reversible by moving one cable.
dhcp-host=70:4B:CA:58:59:8B,192.168.50.120,srt-controller
EOF

sudo nmcli connection up srt-link
```

`shared` mode leases from `.10` upward, and a `dhcp-host` entry takes precedence
within that range, so `.120` is safe.

If another connection profile might claim the new interface, stop it:

```bash
nmcli -f NAME,DEVICE,AUTOCONNECT connection show      # look for "Wired connection 1"
sudo nmcli connection modify "Wired connection 1" connection.autoconnect no
```

**Activation without a cable is expected to succeed** but the interface stays
`NO-CARRIER` until step 6. That is normal.

Check:

```bash
sysctl net.ipv4.ip_forward                  # must be 1
sudo nft list ruleset | grep -i masquerade  # a rule for 192.168.50.0/24
pgrep -af "dnsmasq.*enp5s0"                 # dnsmasq with --conf-dir set
```

---

## 5. Firewall

Ubuntu ships `ufw`. **Check whether it is actually enforcing, and do not trust
`systemctl`:**

```bash
systemctl is-active ufw     # says "active" even when the firewall is OFF
sudo ufw status             # this is the real answer
```

That distinction has caused real confusion — the unit being active says nothing
about whether rules are applied.

Whether or not you enable it, the rules below are the correct set. Add them
first, enable second, and **do it at the console** — enabling a firewall over ssh
is how people lock themselves out.

```bash
sudo ufw limit 22/tcp                    comment 'ssh (rate limited)'
sudo ufw allow in on enp5s0              comment 'SRT private link (single trusted device)'
sudo ufw route allow in on enp5s0 out on eno1 comment 'SRT link NAT out'

sudo ufw default deny incoming
sudo ufw default allow outgoing
sudo ufw default deny routed

sudo ufw enable
```

Two of those are non-obvious and both were learned the hard way:

- **`route allow … out on eno1` is what keeps the controller's clock working.**
  The default forward policy is deny, which silently blocks the NAT. The
  controller then never syncs time again and the mount mispoints overnight.
- **`allow in on enp5s0` is what keeps OTA firmware updates working.** `espota`
  sends its invitation to the controller and then expects the controller to
  connect *back* to the host on an **ephemeral** port — a different one every
  run — so it cannot be allowed by port number. Without this rule the upload
  fails with the unhelpful `No response from device`, because the invitation
  succeeds and only the callback is blocked. Trusting the link interface as a
  whole is reasonable: it carries exactly one device, on a subnet this host owns
  and serves.

Nothing needs an inbound rule on the site interface. In particular **do not open
port 5000** — see section 7.

---

## 6. Move the controller

This is the only moment with any risk, and it is a cable's width of risk.

Move the controller's Ethernet cable from the site switch to the new card. The
controller handles link-down/link-up, re-runs DHCP, and re-arms its time sync on
every `GOT_IP`. Nothing on it is reconfigured.

```bash
journalctl -u NetworkManager -f      # watch for DHCPACK … 192.168.50.120
```

**If anything misbehaves, move the cable back.** That restores the previous state
exactly. Second fallback is the controller's WiFi AP (`SRT_Controller`, at
`192.168.4.1`), which stays up regardless of Ethernet settings.

---

## 7. Software configuration

**Scheduler runtime config** — `receiver_scheduler/scheduler_config.json` is
gitignored and is the runtime source of truth:

```json
"srt_controller_url": "http://192.168.50.120",
"srt_controller_fallback_urls": ["http://srt-controller.local",
                                 "http://192.168.4.1"]
```

Set it through the scheduler's Configuration tab or `POST /api/config` so the
running process and the file agree. The scheduler restricts CORS to these
origins, so if they do not match the address the controller's page is served
from, the scheduler buttons embedded in that page stop working with no error
beyond a browser console message.

**The scheduler binds loopback, and must stay that way.** It has no
authentication of any kind, and its endpoints start observations, take the SDR,
rewrite the schedule, push a pointing model and **flash controller firmware over
OTA**. Bound to `0.0.0.0` that is an unauthenticated telescope-control API
offered to every network the host is attached to. Nothing needs the wildcard: the
controller's own page fetches the scheduler at `127.0.0.1:5000` from a browser
running on this host, and remote use is over waypipe, which forwards the display
rather than the connection.

**The scheduler is deliberately not a service.** It starts from the desktop
**Start SRT Software** launcher, which runs `receiver_scheduler/start_scheduler.sh`
(until 2026-10-01 it did so through the VS Code workspace's `folderOpen` task,
which still runs it when the workspace is opened by hand). That wrapper reuses an
already-serving scheduler instead of starting a second one that would die on the
bound port. Do not add a systemd unit: it would contend with the launcher for port
5000, and the scheduler should not come up unattended.

**Firmware defaults** — if you changed the subnet, update `DEFAULT_ETH_STATIC_IP`,
`DEFAULT_ETH_GATEWAY`, `DEFAULT_ETH_SUBNET` and `DEFAULT_ETH_DNS` in
`esp32_controller_arduino/src/config.h`. These are only used if someone turns
DHCP off in the web UI, but they are what that form is pre-filled with — left
pointing at another subnet, one tick of that box moves the controller off the
link entirely.

**OTA target** — `esp32_controller_arduino/platformio.ini`, `[env:wt32-eth01-ota]`,
`upload_port = 192.168.50.120`.

---

## 8. Verify

Run from the observatory computer.

```bash
ping -c3 192.168.50.120
curl http://192.168.50.120/ping        # -> ok
curl http://192.168.50.120/network     # eth_ip, and the DNS diagnostics
curl http://192.168.50.120/status      # live alt/az JSON
getent hosts srt-controller.local      # mDNS, needs avahi on the host
```

Then the two that are easy to get wrong.

### Proving the route out actually works

**`/time/status` reporting `"source":"NTP"` does not prove the link routes.** The
firmware carries a numeric NTP fallback behind the pool name, so the clock syncs
whether or not DNS works — it will report `NTP` on a host that cannot resolve
anything. It is a true statement about the clock and a useless one about the
network.

What proves it is a **fresh sync after a reboot**. Reboot the controller (an OTA
upload will do it), then:

```bash
curl http://192.168.50.120/time/status
```

`sync_count` must have **reset to 1** — that confirms you are looking at a real
reboot and not a stale reading — with a small `last_sync_age_s`. That combination
means SNTP packets left the host, reached a time server and came back.

### Proving DNS works

Turn on query logging temporarily:

```bash
echo 'log-queries' | sudo tee -a /etc/NetworkManager/dnsmasq-shared.d/srt.conf
sudo nmcli connection down srt-link && sudo nmcli connection up srt-link
journalctl -u NetworkManager -f | grep -E "query|reply"
```

Reboot the controller and watch for `query[A] pool.ntp.org from 192.168.50.120`
followed by replies. Remove the `log-queries` line afterwards or the journal
fills slowly.

The firmware also reports its own view, which needs no logging at all:

```bash
curl http://192.168.50.120/network
```

| Field | Meaning |
|---|---|
| `dns_after_eth` | resolver right after Ethernet DHCP — should be `192.168.50.1` |
| `dns_after_wifi` | resolver after WiFi startup — **`0.0.0.0` is expected** |
| `lwip_dns0` | the resolver in use now — should hold `192.168.50.1` |
| `dns_restores` | repair count, climbs slowly — **normal, not a fault** |

That `dns_after_wifi` reading is not a bug report: lwIP's resolver list is
process-wide rather than per-interface, and bringing the WiFi AP up clears it,
repeatedly. The firmware caches the address DHCP supplies and puts it back
whenever it finds the list empty (issue #11). The field is sampled *before* the
repair on purpose, so it keeps showing the underlying behaviour. If it ever shows
a real address, the core was fixed upstream.

### Finally

```bash
cd esp32_controller_arduino && ~/.platformio/penv/bin/pio run -e wt32-eth01-ota -t upload
```

OTA is the check that most depends on the firewall being right, so run it once
deliberately rather than discovering it when you need it.

Stellarium: telescope type "External software or remote computer", host
`192.168.50.120`, port `10001`.

---

## 9. Recovery

The controller has two independent safety nets, so a wrong address is not a
bricking risk:

1. **Move the cable back to the site switch.** Because the controller was never
   reconfigured, this restores the previous state exactly.
2. **The WiFi AP stays active** — SSID `SRT_Controller`, web UI at
   `http://192.168.4.1` — regardless of what the Ethernet settings say.
3. Invalid static configuration falls back to DHCP, so a malformed address leaves
   the controller reachable rather than dark.
4. Last resort is the FT232-and-buttons serial flash at the telescope, in
   [WT32_ETH01_MIGRATION.md](WT32_ETH01_MIGRATION.md).

To roll back completely: reach the UI over the AP, confirm Ethernet is on DHCP,
move the cable to the site switch, power-cycle, and put the site address back in
the scheduler config.

---

## 10. Remote access

Neither web UI is reachable from the network, and that is the design: the
controller sits on the private link where only this host can see it, and the
scheduler binds loopback (section 7). So remote access means reaching them
*through* this host rather than exposing them.

### The web UIs: an ssh tunnel

Both are just web pages, so this needs no graphical forwarding at all. From the
remote machine:

```bash
ssh -L 8080:192.168.50.120:80 -L 5000:127.0.0.1:5000 astro@ettus3.astro.gla.ac.uk
```

Then, in a browser on the remote machine:

| | |
|---|---|
| `http://localhost:8080` | controller UI |
| `http://localhost:5000` | scheduler |

This works because the ssh session terminates *on the observatory host*, so the
forwards originate from the one machine that can see both the private link and
the loopback-bound scheduler. Nothing new is exposed: the tunnel is
authenticated by the ssh login, and both services stay unreachable from the
network.

**Forward port 5000 as well, even if you only want the controller.** The
controller's own page fetches the scheduler at `http://127.0.0.1:5000` for its
Scheduler link, Sun Scan and Calibration Day buttons and the firmware update
control. Through a tunnel that resolves to the *remote* machine, so without the
second forward those buttons fail with nothing but a browser console message.

Two mistakes give the same `channel N: open failed` from ssh, and the text after
the colon tells you which:

- `-L 8080:192.168.50.120:8080` — the controller serves on port **80**. The
  remote port is 80; only the local one is 8080.
- Forwarding to the scheduler while it is not running. `connect failed:
  Connection refused` means the far end had nothing listening. Note the
  scheduler does not start at boot by design, so after a reboot there is nothing
  on port 5000 until the launcher has been used.

### Applications: waypipe

For anything that genuinely needs a desktop — Stellarium, VS Code, the receiver
GUI — use waypipe, which is installed on the host:

```bash
waypipe ssh astro@ettus3.astro.gla.ac.uk stellarium
```

The client needs waypipe too, and a Wayland session. **From WSL2 that means
WSLg** (Windows 11, or Windows 10 with a recent WSL): install `waypipe` inside
the WSL distribution and check `echo $WAYLAND_DISPLAY` returns something.
Compare `waypipe --version` at both ends, since mismatched versions can fail to
connect. Expect it to be usable but not fast — waypipe's dmabuf and video
acceleration do not survive the hop into WSLg, so it falls back to software
transfer.

## 11. What this does not do

**Access from other machines on the site network is not set up**, deliberately.
The host NATs *outbound* for the controller; nothing routes inbound. If someone
else needs the controller UI, the host needs a forwarding rule or a reverse
proxy — which partly re-exposes the thing the private link was meant to protect.
Use the ssh tunnel in section 10 instead.

**Nothing here depends on the site interface's address.** The masquerade rule
matches on the link subnet, the ufw rules name interfaces rather than addresses,
and `never-default` keeps the link out of the routing decision. The site
interface can be renumbered, moved to a different socket, or switched between
DHCP and a static address, and the controller will not notice — verified on
2026-08-21 by moving this host from a DHCP 192.168.106.x address to a static
public one, after which the controller's clock still synced on the first reboot.

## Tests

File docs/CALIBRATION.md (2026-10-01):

# How this telescope is calibrated

Written for whoever has to reduce, extend or distrust the numbers this
telescope produces. It says what each calibration measures, what it cannot
measure, where it is applied, and how to undo it.

**The governing rule: a recording is always exactly reversible.** Every
correction applied on the way to disk is stored beside the data it was applied
to, and `observation_plot.read_observation` multiplies all of them back out, so
the pipeline always works in raw counts. Spectra are written in kelvin for
whoever opens the file in a notebook; they are never *only* in kelvin. A
calibration that could not be undone would make every later improvement a
re-observation.

Read §1 and §2 first. §3–§6 are the detail behind each step, §7–§9 are where
the numbers end up, and the appendix records designs that were tried and are
worse, so nobody rebuilds them.

---

## 1. What has to be measured

A recorded spectrum is

```
counts(f, t)  =  G(t) · B(f, t) · [ T_sys(t) + g(t) · T_A(f, t) ]
```

| term | is | measured |
|---|---|---|
| `T_A` | the sky — the thing we want | — |
| `T_sys` | everything the instrument and its surroundings add: the SAWbird's 59 K, spillover onto the ground, the atmosphere, the cable | 187.7 K (l=72 b=0, 2026-09-30); 340–372 K on the old feed, before 2026-09-22 |
| `B(f, t)` | the **shape** of the response across the band, normalised to unit median: the SAW filter's passband, and that filter's multi-transit echo ripple | — |
| `G(t)` | the **level**, counts per kelvin | 1.460×10⁻⁷ (same fit); ~8–9×10⁻⁷ on 2026-09-15/16, not comparable: those fits were at 30 dB receiver gain (20 dB from 2026-09-17) and through the old feed (replaced 2026-09-22) |
| `g(t)` | the **beam's gain on the source**, where the source is small against the beam: 1 when the beam is centred, less when the mount is pointed off | 0.98–1.00 |

Note where `g` sits in that line. It multiplies `T_A` and **not** `T_sys`,
because the system temperature does not care where the dish is looking. Every
other term multiplies the whole bracket. That one difference decides the order
everything is applied in, and getting it wrong costs the ratio of the two —
22% on the Sun.

Five calibrations measure these, on five different timescales, and a sixth
converts kelvin to flux.

| what | measures | good for | where |
|---|---|---|---|
| bandpass template | `B(f)` | days, and it goes stale | `bandpass.py` |
| gain and system temperature | `G`, `T_sys` | hours | `rf_calibration.py` |
| pilot bursts | changes in `G` and `B(f)` | one burst per 60 s of run, duty permitting | `pilot.py` |
| pilot carrier | fast common-mode `G` | every record | `pilot.py` |
| tracking scallop | `g(t)` on a tracked compact source | one observation, fitted from its own records | `scallop.py` |
| beam solid angle | kelvin → flux | once, per feed | `astro_simulator/instrument.py` |

The first two are **measured beforehand, on separate jobs, and stored on
disk**. The two pilot calibrations are **measured inside the observation
itself**, at write time — when the pilot is enabled, which it has not been by
default since 2026-09-22 (§3). The scallop is measured inside the observation too,
but **afterwards, in the reduction** — everything it needs is derivable from
the file, so it is never written and an old recording improves the day the
pointing model or the measured beam does. The beam solid angle is measured
once and rarely changes.

---

## 2. The whole chain in one pass

What happens to one observation, in order. Each step names the section with
the detail.

**Before the run**

1. A **bandpass job** tracks the Lockman Hole, records a few minutes, fits a
   polynomial to the mean spectrum with the line masked, and stores
   `bandpass_template.json` and `bandpass_template_wide.json`. Since
   2026-09-25 the same fit can be made from a recording already on disk
   (`/api/rf/bandpass/from-recording`). A new template stales the gain. (§5)
2. A **gain job** tracks a plane field, records, and fits `counts = G·(T_sys +
   T_model)` against the simulator's sky. Stores `gain_calibration.json`. (§5)

**At start-up of the observation**

Steps 3, 4 and 6–9 run only with the pilot enabled. It is off by default
since 2026-09-22 (§3); with it off, steps 5 and 10 are the whole write-time
chain.

3. The receiver builds the **pilot plan** from the tuning: which wide bins
   carry comb tones, the two transmit frames, and the reference spectrum the
   recovery correlates against. (§3)
4. It converts `burst_interval_s` into a **burst every N records** using this
   observation's integration time, floored by the duty cap. (§3)
5. It copies the stored template and gain into the file as
   `bandpass_correction`, `applied_gain_counts_per_k`, `applied_t_sys_k`, and
   writes every attribute, so the file is complete before the first record and
   can be opened SWMR while it is still being written. (§7)

**Per record, during the run**

6. The transmitter sends the **carrier** continuously. On a burst record it
   also sends the **comb**, switched off `burst_off_margin_s` before the
   record ends. (§3)
7. A gate decides, per 20 ms block, whether the comb is present, **by the
   comb's own coherent signature**. On-blocks accumulate a cross-spectrum;
   off-blocks accumulate the noise. (§4)
8. At the end of a burst record the accumulation is turned into a **complex
   response per comb bin**, `h`. (§4)
9. From `h` against the reference: a **level** and **slope** applied to the
   records up to the next burst, and a **passband correction vector** averaged
   over the bursts of the last half hour. The carrier's power gives a flat
   per-record factor, recorded but not applied. (§6)
10. The science record is divided by bandpass × gain × pilot factors, `T_sys`
    subtracted, and written in kelvin — with every factor stored beside it.
    Burst records are written uncorrected and flagged. (§7)

**Afterwards, in the reduction**

11. `read_observation` multiplies all of it back, drops the burst records, and
    hands back counts — **except the pilot when asked for `keep_pilot=True`**,
    which a plot does and a fit does not, because the pilot is the only
    correction that cannot be rebuilt from the file. (§8, §10)
12. The bandpass and the gain are re-applied from the stored template, `T_sys`
    is subtracted, and the channels outside the continuum window are dropped.
    What is left is **antenna temperature**. (§5)
13. On a tracked compact source, the **tracking scallop** — the beam walking
    ±0.25° across the source as the drive crosses encoder pulses — is fitted
    from the run's own records and divided out. This is `g(t)` from §1, so it
    happens **here**, after `T_sys` is subtracted, and never on the counts.
    (§5)
14. Kelvin becomes flux through the measured beam solid angle, and solar work
    is corrected to above the atmosphere. (§5)
15. Plots and fits say on their face what was and was not applied — which
    pointing model the scallop used, how many records the pilot reached, and
    the reason whenever either was refused. (§9)

Steps 11–15 are all reversible-by-omission: none of them writes to the
recording, so a file re-reduces from scratch every time and improves when the
template, the pointing model or the measured beam does.

---

## 3. What is injected, and when

The pilot is the receiver's own reference: the B200's transmitter, through
fixed pads and the old SRT calibration dipole at the dish's vertex, radiating
into the feed so that **everything downstream of the feed is inside the
measurement** — the probe, the horn, the SAWbird, the cable down the mount,
the converter. Detail in `receiver_scheduler/pilot.py`; the design record is
issue #30.

**Status: off by default since the evening of 2026-09-22**
(`PILOT_DEFAULTS["enabled"] = False`; `receiver_pilot_enabled: false` in the
live config). The dipole was wired that afternoon — a 30 dB pad, an axial
stub, `receiver_pilot_tx_gain_db` 70 in the live config against the
`tx_gain_db` default of 10 — and the first sky runs showed the carrier's
received level stepping by up to 1.6% at every host stall (a TX underflow with
an RX overflow, counted per record in `underflows`) and staying there, and
drifting three times as far as the receiver between stalls (r = 0.97 in
shape). Dividing by it makes a series worse. The bursts are unproven. What
follows is the design as built; it is parked in issue #46.

**Enabling the TX chain costs 8.4% of receiver sensitivity**, instantly, in
both products, whatever the TX gain: an A-B-A on l=84 b=4 on 2026-09-22 read
8.41 ± 0.01% (continuum) and 8.53 ± 0.02% (H I) higher with the TX off than
on, the two on-legs agreeing to 0.3%, and a leg
with the TX enabled at 0 dB sat at the 70 dB level to 0.02%. It is the
AD9364's state with its transmitter on, not the radiated carrier. A further
~1.5% start-up transient with a few-minute time constant rides on top when the
TX is on. So a gain belongs to one TX state, and **the pilot is never toggled
per observation**: a recording made in the other state reads 8.4% off the gain
in force, and its kelvin are wrong by that much though nothing flags it.

Two things are transmitted, and they are transmitted from **separate sources**
that are added together, so switching one never disturbs the other.

### The carrier — continuous

One tone at **1415.3 MHz**, in every record including the burst records, at
`tone_amplitude` (0.0791 of DAC full scale).

**Its amplitude is not independent of the comb's.** Both come off one transmit
chain and one sink, so `tx_gain_db` moves them together — and the carrier runs
in *every* record, not just the bursts. A CW tone has a crest factor of 1.0
while the comb is peak-limited by its Schroeder crest of 1.35, so at equal
amplitudes the carrier is far from negligible: at the old 0.25 it was 46% of
the comb's mean power, putting 2.24× the whole band's noise power in the band
continuously. When the transmit gain went up 10 dB on 2026-09-17 the amplitude
was divided by √10 to hold the carrier exactly where it was. Left alone it
would have reached 23× of band noise in every science record — most of the
headroom the receiver-gain change had just bought, and a strong in-band CW
tone is the classic source of intermodulation products, which land back across
the measured band rather than staying in their own unmeasured bin.

It sits in the 800 kHz between the low edge of the sampled band and the
continuum band, where nothing is measured, so no exclusion machinery is
needed; the analogue bandwidth is twice the sample rate, so nothing rolls off
there. It does sit in the SAW skirt, which is why it carries only the *fast*
part of the gain — the bursts track the skirt's own slow motion.

It exists because a burst measures the gain at one instant a minute, while the
common-mode wobble (`GAIN_INSTABILITY`, 2.3×10⁻⁴ per 60 s record) is white on
that timescale. That is the one regime where neither per-channel thermal
averaging nor a switched reference saves an unswitched band-integrated drift
scan.

### The comb — in bursts

A **full-band comb**, one tone on every wide bin except the LO guard
(`dc_guard_bins`, 4) and the carrier's neighbourhood (`tone_guard_bins`, 6),
at `burst_amplitude` (0.5 of full scale), with Schroeder phases so the crest
factor is ~√2 and the burst carries its power without hitting the rails.

It runs for the length of **one whole record**, switched off
`burst_off_margin_s` (0.3 s, capped at a quarter of the record) before the
record ends. That record is flagged `pilot_burst = 1` and **dropped from the
science** by `read_observation`. Every other record carries no comb at all —
nothing to exclude, subtract or explain.

### How often a burst is sent

**The cadence is a time, not a record count.** A record is not a fixed
length — 3 s on a solar track, 10 s on a calibration field, 60 s on a drift
scan — so "every twentieth record" would mean a burst a minute in one case and
one every twenty minutes in another. The configuration asks for an interval in
seconds (`burst_interval_s`, 60 s) and `pilot.burst_every()` converts it at
start-up. But **a burst costs one whole record whatever its length**, so the
interval and the cost cannot both be held: `max_duty_cycle` (5%) takes over at
long integrations.

| record length | burst every | cost |
|---|---|---|
| 0.5 s | 60 s (120 records) | 0.8% |
| 3 s | 60 s (20 records) | 5% |
| 10 s | 200 s (20 records) | 5% |
| 60 s | 20 min (20 records) | 5% |

So an observation that needs a tighter calibration cadence should use
**shorter records** — the plots bin them back down anyway — rather than pay a
larger fraction of its samples. That matters most for the tilt, which is only
measured at bursts: on a drift scan the continuum band sits entirely on one
side of the anchor, so a tilt changing by 0.1%/MHz between bursts moves the
band mean by 0.17%.

**A pilot that is never detected is given up on** after `give_up_after_bursts`
(5), since it otherwise costs one record an interval for nothing — the state
of every run before the vertex dipole was wired. The carrier keeps running, costing
no records. A pilot seen even once is never given up on: an intermittent one
is a fault to record, not a reason to stop measuring.

---

## 4. How it is recovered

### Deciding a block holds the comb

Per 20 ms block, the statistic is the **height of the cross-spectrum's delay
peak against that block's own noise**. The fixed framing offset between
transmit and receive puts a phase ramp across the band, so the inverse
transform of the cross-spectrum peaks at that offset; the peak against the
block's own noise is an absolute measure.

| | statistic |
|---|---|
| no comb | 2.6 σ (the expected maximum of 1024 Rayleigh draws) |
| a twentieth of the block covered | 32 σ |
| the whole block | 286 σ |
| the whole block, Sun in the beam | 286 σ |

Threshold `gate_sigma` = 8. **Nothing is compared with a running baseline and
nothing depends on how bright the sky is**, which is what makes it safe — see
the appendix for the two designs that did depend on one.

A block is committed only when it and both its neighbours agree, which drops
the partial block at each burst edge: two blocks in 150, where counting a
partial one as whole would bias the response by up to 1.3%. On-blocks
accumulate `Σ F conj(R)`; off-blocks accumulate the noise power per bin.

**Do not put the gate's arithmetic in the Python block.** The first version did
it per frame and cost 55–70% of a core, because GNU Radio hands a 1024-point
vector sink 3.2 frames a call whatever `set_min_noutput_items` asks. The
multiply, the magnitude and both integrations are C++ blocks; the Python sink
runs at 50 Hz. Measured with the pilot exactly as a scheduled observation runs
it, 90 s with 9 bursts: zero overflows, zero underruns, 2.65 cores of 8.

### Turning the accumulation into a response

`pilot.estimate()` takes the accumulated cross-spectrum, the frame count and
the off-block noise, finds the framing offset from the peak of the inverse
transform and removes it, and returns

- `h`, the chain's complex **field** response per comb bin,
- `snr` per bin and its median.

Three details that each cost a rewrite:

- **The recovery has its own unwindowed FFT.** The frame is periodic at
  exactly the transform length, so under a rectangular window it has no
  leakage and the reference is flat across the band. Through the wide
  product's Blackman-Harris window the reference instead follows the window in
  *time*, and since a swept chirp maps time to frequency, it falls to zero at
  both band edges — exactly where the filter's tilt must be measured.
- **Everything applied to counts is a power.** `h` is a field response and
  counts are powers, so the ratio is `|h|²`. Fitting the amplitude ratio and
  applying it to counts would be wrong by a square: a factor of two in the
  departure from unity, invisible at the percent level.
- **The reference matters.** `h` is compared against `pilot_reference` — the
  calibration's stored reference where the gain job has written one (not yet),
  otherwise the run's own first detected burst, with `pilot_anchored = 0` to
  say so. Self-referenced, the pilot removes drift *within* a run but not the
  offset from the calibration.

---

## 5. The measurements that do not come from the pilot

### The bandpass template

A polynomial in frequency, fitted to the mean spectrum of the emptiest
hydrogen field in the northern sky (the Lockman Hole, l=150 b=+52, 1.3 K of
H I) with the line masked. Normalised to unit median over the band it was
fitted on, so dividing by it flattens the band without moving its level: the
counts-to-kelvin scale is a separate matter, deliberately not folded in.

**Two templates, one scale.** `bandpass_template.json` for the H I product,
`bandpass_template_wide.json` for the continuum product. The wide one is
normalised over the *H I* band, so the single gain — fitted on the H I
product — is the right scale for both.

**It refuses rather than warns.** A template's polynomial is a function of
frequency *relative to the local oscillator it was fitted at*, and the
hardware's passband moves with the oscillator. Evaluated at a different tuning
it still returns finite numbers over whatever frequencies overlap: retuning by
1.4 MHz once left 60% of channels "covered" by a shape displaced from the real
passband and marked valid. So `bandpass.applies_to` checks the tuning, and a
mismatch leaves the file in counts.

**What it checks is the LO and the sample rate, not the receiver gain** —
unlike the gain calibration, which refuses on all three. That is defensible:
the template is normalised to unit median, so it carries shape alone, and an
amplifier's compression responds to the *total* power through it and takes the
whole band down together, which divides out of a normalised shape. It is not
proven, though, and the second-order term has never been measured. Re-measure
the template after a receiver-gain change anyway: nothing refuses a template
fitted at another gain, and it would be applied silently.

**In force:** order 9, fitted 2026-09-30 by a live job on l=150 b=+52
(38 records, 20 dB, TX off), residual 0.18% (H I) and 0.14% (wide).

**From a recording on disk.** Since 2026-09-25 the RF tab can fit both
templates from a finished recording (`/api/rf/bandpass/from-recording`): a
tracked spectrum at the instrument in force (LO, rate and receiver gain all
checked), Sun runs refused. A template wants a long, high-latitude, TX-off
run chosen after the fact, which a few minutes of live job on whatever sky is
up cannot always give. The template in force from 09-22 to 09-25 was a
37-record live job with the TX on; its 0.5 K error was the S-shaped residual
on every spectrum in between, correlated 0.84–0.97 across plane fields, and
gone when a 601-record TX-off run at l=71.7 b=+44 replaced it.

`bandpass.fit_from_observation` **writes the template in force** unless called
with `save=False`; an experiment overwrote it on 09-25. And **the template and
the gain are a pair**: the gain was fitted through the template, so replacing
the template stales the gain, and the gain must be refitted after it.

**What it cannot do, and the reason the pilot exists:** the SAW filter is
outdoors on the dish, its substrate drifts tens of parts per million per
degree, and its echo ripple — 0.1–0.15% of the passband at a 160 kHz period —
correlates 0.83 within a run, 0.80 within an evening and only 0.55 from one
day to the next. A stored template cannot follow it, and it is the dominant
residual of a gain fit: 0.48 K against a 0.15 K thermal floor.
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

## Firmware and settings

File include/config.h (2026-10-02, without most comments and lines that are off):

#define CONFIG_H
#define PIN_FF2_AZ      4       // Azimuth Fault Flag 2 (purple)
#define PIN_FF1_AZ      5       // Azimuth Fault Flag 1 (blue)
#define PIN_FF2_ALT     6       // Altitude Fault Flag 2 (purple)
#define PIN_FF1_ALT     7       // Altitude Fault Flag 1 (blue)
#define PIN_RESET_AZ    22      // Azimuth driver reset (black)
#define PIN_RESET_ALT   24      // Altitude driver reset (white)
#define PIN_PWM_AZ      8       // Azimuth motor PWM (green)
#define PIN_PWM_ALT     10      // Altitude motor PWM (green)
#define PIN_DIR_AZ      9       // Azimuth direction (yellow)
#define PIN_DIR_ALT     11      // Altitude direction (yellow)
#define AZ_DIR_INVERT   1       // 1 = invert azimuth direction sense
#define ALT_DIR_INVERT  1       // 1 = invert altitude direction sense
#define PIN_PULSE_AZ    12      // Azimuth encoder (yellow)
#define PIN_PULSE_ALT   13      // Altitude encoder (blue)
#define PIN_CURRENT_AZ  A1      // Azimuth current sensor (black)
#define PIN_CURRENT_ALT A0      // Altitude current sensor (white)
#define DEFAULT_ALT_HW_MIN      0.0     // Altitude lower hardware limit (limit switch)
#define DEFAULT_ALT_HW_MAX      90.0    // Altitude upper limit (encoder count only - no switch)
#define DEFAULT_AZ_HW_MIN       0.0     // Azimuth lower hardware limit (limit switch)
#define DEFAULT_AZ_HW_MAX       355.0   // Azimuth upper hardware limit (limit switch)
#define DEFAULT_ALT_MIN         0.0     // Altitude lower software limit
#define DEFAULT_ALT_MAX         90.0    // Altitude upper software limit
#define DEFAULT_AZ_MIN          2.0     // Azimuth lower software limit (2 deg inside HW)
#define DEFAULT_AZ_MAX          353.0   // Azimuth upper software limit (2 deg inside HW)
#define SOFTWARE_LIMIT_TOLERANCE 4.0
#define DEFAULT_HOME_ALT        0.0     // Altitude home position
#define DEFAULT_HOME_AZ         0.0     // Azimuth home position
#define DEFAULT_RAMP_UP_MS      500     // Time to reach full speed (ms)
#define DEFAULT_RAMP_DOWN_DEG   7.0     // Start decel this many degrees before target
#define DEFAULT_STOP_RAMP_MS    300     // Time to stop before reversing (ms)
#define DEFAULT_CURRENT_LIMIT   5.0     // Stop motor if current exceeds this (Amps)
#define DEFAULT_STALL_TIMEOUT   2000    // No pulses for this long = stalled (ms)
#define HOMING_SETTLE_MS        400     // After the homing back-off: no pulse for this long = coast over
#define REVERSAL_SETTLE_MS      400
#define HOMING_SLOW_APPROACH_PULSES 5   // Creep from this many pulses out (2.5 deg): enough that a fast first approach's overshoot still leaves the switch inside the creep
#define HOMING_SLOW_BRAKE_MS        400
#define HOMING_CREEP_CURRENT_A      0.3     // driving-direction current above which the axis is driving
#define DEFAULT_BACKLASH_AZ     0.0     // Azimuth backlash compensation (degrees)
#define PULSES_PER_DEGREE   2       // Encoder resolution
#define DEFAULT_DEBOUNCE_MS     50   // Azimuth: minimum time between valid pulses
#define DEFAULT_DEBOUNCE_ALT_MS 100  // Altitude: minimum time between valid pulses
#define PWM_STOP            255     // Motor stopped (inverted logic)
#define PWM_FULL_SPEED      0       // Motor at maximum speed
#define PWM_MIN_SPEED       100     // Minimum speed during ramp
#define CURRENT_SENSOR_OFFSET_V     1.65    // Zero-current voltage (mid-rail, 3.3V/2)
#define CURRENT_SENSOR_SENSITIVITY  0.044   // V/A (44mV/A, bipolar)
#define ADC_REFERENCE_V             3.3     // Due native ADC reference
#define ADC_RESOLUTION_BITS         4096    // 12-bit ADC (2^12)
#define CONFIG_MAGIC        0x53525431  // "SRT1" - to validate stored config
typedef struct {
    uint32_t magic;             // Magic number to validate config
    float altHwMin;
    float altHwMax;
    float azHwMin;
    float azHwMax;
    float altMin;
    float altMax;
    float azMin;
    float azMax;
    float homeAlt;
    float homeAz;
    uint16_t rampUpMs;          // Acceleration time
    float rampDownDeg;          // Deceleration distance in degrees
    uint16_t stopRampMs;        // Reversal deceleration time
    float currentLimit;         // Overcurrent threshold (Amps)
    uint16_t stallTimeoutMs;    // Stall detection timeout
    uint16_t debounceMs;        // Azimuth encoder pulse debounce time
    uint16_t debounceAltMs;     // Altitude encoder pulse debounce time
    float backlashAzDeg;        // Azimuth backlash compensation (degrees)
    uint32_t checksum;          // Simple checksum for validation
} Config;
#define SERIAL_BAUD         115200
#define STATUS_INTERVAL_MS  1000    // Status output every 1 second
#define ENABLE_SERIAL1      1       // Set to 0 to disable Serial1
#define MAIN_LOOP_DELAY_MS  10      // Main loop period
#ifdef SIMULATION_MODE
#define SIM_MAX_SPEED_DEG_S     180.0   // Simulated max motor speed (degrees/second) - fast for testing
#define SIM_INITIAL_AZ_DEG      20.0    // Starting azimuth before homing (degrees) - close to limit
#define SIM_INITIAL_ALT_DEG     10.0    // Starting altitude before homing (degrees) - close to limit
#define SIM_STALL_TIMEOUT_MS    200     // Faster stall detection in simulation (ms)
#endif // SIMULATION_MODE

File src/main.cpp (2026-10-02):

/**
 * SRT Motor Driver
 *
 * Controls alt-az drive for Small Radio Telescope.
 * Arduino Due with H-bridge motor drivers and reed switch encoders.
 *
 * Serial Commands:
 *   DRIVE <alt> <az>     - Slew to position (or just: <alt> <az>)
 *   HOME                 - Run homing sequence
 *   STOP                 - Emergency stop
 *   STATUS               - Show current status
 *   CONFIG               - Show all configuration
 *   SET <param> <value>  - Set configuration parameter
 *   SAVE                 - Save configuration to flash
 *   LOAD                 - Load configuration from flash
 *   DEFAULTS             - Reset to factory defaults
 *   HELP                 - Show command help
 *
 * ESP32 Bridge (WT32-ETH01 via Native USB):
 *   Serial output from ESP32 is forwarded to Native USB port for monitoring
 */

#include <Arduino.h>
#include <DueFlashStorage.h>
#include <math.h>
#include "config.h"

// Azimuth direction inversion: motor is wired in reverse
#if AZ_DIR_INVERT
#define AZ_DIR(level)  ((level) == HIGH ? LOW : HIGH)
#else
#define AZ_DIR(level)  (level)
#endif

// Altitude direction inversion: motor is wired in reverse
#if ALT_DIR_INVERT
#define ALT_DIR(level)  ((level) == HIGH ? LOW : HIGH)
#else
#define ALT_DIR(level)  (level)
#endif

// =============================================================================
// ESP32 SERIAL COMMUNICATION (WT32-ETH01)
// =============================================================================
// The Due communicates with the WT32-ETH01 via Serial1 (pins 18/19).
// The Native USB port (SerialUSB) bridges to Serial1 for monitoring.
//
// Hardware connections (directly, no level shifter needed - both 3.3V):
//   Due Pin 18 (TX1) -> WT32-ETH01 IO14 (ESP32 RX)
//   Due Pin 19 (RX1) <- WT32-ETH01 IO4  (ESP32 TX)
//   GND              -- GND
//
// Note: IO4/IO14 are used instead of IO32/IO33 because some WT32-ETH01
// variants have IO32/IO33 labelled CFG/485_EN for RS-485 circuitry.
// =============================================================================

#define ESP_BRIDGE_ENABLED  1       // Set to 0 to disable bridge functionality
#define ESP_BRIDGE_BAUD     115200  // Baud rate for ESP32 serial monitoring

// =============================================================================
// SIMULATION MODE - Override hardware I/O with software stubs
// =============================================================================
//
// When SIMULATION_MODE is defined, all motor control I/O is intercepted by
// shadow variables. simulatePulses() generates position feedback based on
// the commanded PWM speed, closing the control loop without real hardware.
//
// Build with: pio run -e simulation
// =============================================================================

#ifdef SIMULATION_MODE

// Shadow state for motor control outputs
static int simPwmAz = PWM_STOP;
static int simPwmAlt = PWM_STOP;
static bool simDirAz = true;    // true = HIGH (East/Up)
static bool simDirAlt = true;

// Fractional pulse accumulators
static float simAccumAz = 0.0f;
static float simAccumAlt = 0.0f;
static unsigned long simLastUpdateMs = 0;

// Override analogWrite - capture PWM values instead of hitting hardware
static void simAnalogWrite(uint32_t pin, uint32_t val) {
    if (pin == PIN_PWM_AZ)       simPwmAz = val;
    else if (pin == PIN_PWM_ALT) simPwmAlt = val;
}
#define analogWrite(pin, val) simAnalogWrite(pin, val)

// Override digitalWrite - capture direction state, but pass through ESP bridge pins
static void simDigitalWrite(uint32_t pin, uint32_t val) {
    if (pin == PIN_DIR_AZ)       simDirAz = (val == AZ_DIR(HIGH));
    else if (pin == PIN_DIR_ALT) simDirAlt = (val == ALT_DIR(HIGH));
    else {
        // Pass through to real hardware for non-motor pins (ESP bridge, etc.)
        PIO_SetOutput(g_APinDescription[pin].pPort, g_APinDescription[pin].ulPin,
                      val, 0, PIO_PULLUP);
    }
}
#define digitalWrite(pin, val) simDigitalWrite(pin, val)

// Override digitalRead - return no-fault state for motor pins, real read for others
static int simDigitalRead(uint32_t pin) {
    if (pin == PIN_FF1_AZ || pin == PIN_FF2_AZ || pin == PIN_FF1_ALT || pin == PIN_FF2_ALT) {
        return LOW;  // Fault flags LOW = no fault
    }
    // Real read for other pins
    return (PIO_Get(g_APinDescription[pin].pPort, PIO_INPUT, g_APinDescription[pin].ulPin) ? HIGH : LOW);
}
#define digitalRead(pin) simDigitalRead(pin)

// Save reference to real analogRead before we override it
static inline int realAnalogRead(uint32_t pin) {
    return analogRead(pin);
}

// Override analogRead - read real ADC for current sensors, stub others
static int simAnalogRead(uint32_t pin) {
    if (pin == PIN_CURRENT_AZ || pin == PIN_CURRENT_ALT) {
        return realAnalogRead(pin);
    }
    // Other analog pins: return mid-rail
    return (int)((CURRENT_SENSOR_OFFSET_V / ADC_REFERENCE_V) * ADC_RESOLUTION_BITS);
}
#define analogRead(pin) simAnalogRead(pin)

// Override pinMode - no-op for motor pins, real setup for others (ESP bridge)
static void simPinMode(uint32_t pin, uint32_t mode) {
    // Only actually configure non-motor pins (ESP bridge pins 2, 3, etc.)
    if (pin != PIN_PWM_AZ && pin != PIN_PWM_ALT &&
        pin != PIN_DIR_AZ && pin != PIN_DIR_ALT &&
        pin != PIN_PULSE_AZ && pin != PIN_PULSE_ALT &&
        pin != PIN_FF1_AZ && pin != PIN_FF2_AZ &&
        pin != PIN_FF1_ALT && pin != PIN_FF2_ALT &&
        pin != PIN_RESET_AZ && pin != PIN_RESET_ALT) {
        if (mode == OUTPUT) {
            PIO_Configure(g_APinDescription[pin].pPort, PIO_OUTPUT_0,
                          g_APinDescription[pin].ulPin, g_APinDescription[pin].ulPinConfiguration);
        } else {
            PIO_Configure(g_APinDescription[pin].pPort, PIO_INPUT,
                          g_APinDescription[pin].ulPin, g_APinDescription[pin].ulPinConfiguration);
        }
    }
}
#define pinMode(pin, mode) simPinMode(pin, mode)

#define attachInterrupt(a, b, c)    ((void)0)
// analogReadResolution is NOT overridden - real 12-bit ADC needed for current sensors

#endif // SIMULATION_MODE

// Flash storage for configuration
DueFlashStorage flashStorage;

// Active configuration (loaded from flash or defaults)
Config cfg;

// =============================================================================
// FORWARD DECLARATIONS
// =============================================================================

const char* getFaultString();
void outputStatus();
void outputStatusIfChanged();

#if ESP_BRIDGE_ENABLED
void setupESPBridge();
void handleESPBridge();
#endif

// =============================================================================
// STATE DEFINITIONS
// =============================================================================

typedef enum {
    STATE_INIT,
    STATE_HOMING,
    STATE_IDLE,
    STATE_DRIVING,
    STATE_FAULT
} SystemState;

typedef enum {
    FAULT_NONE = 0,
    FAULT_AZ_SHORT,
    FAULT_ALT_SHORT,
    FAULT_AZ_OVERTEMP,
    FAULT_ALT_OVERTEMP,
    FAULT_AZ_UNDERVOLT,
    FAULT_ALT_UNDERVOLT,
    FAULT_AZ_OVERCURRENT,
    FAULT_ALT_OVERCURRENT,
    FAULT_AZ_STALL,
    FAULT_ALT_STALL,
    FAULT_AZ_POSITION_BOUNDS,
    FAULT_ALT_POSITION_BOUNDS,
    FAULT_HOMING_ABORTED        // STOP received during a homing: position unknown until re-homed
} FaultCode;

// =============================================================================
// GLOBAL VARIABLES
// =============================================================================

// System state
volatile SystemState systemState = STATE_INIT;
volatile FaultCode faultCode = FAULT_NONE;

// Position tracking (in pulses, 2 pulses = 1 degree)
volatile int32_t positionAz = 0;    // Current azimuth position
volatile int32_t positionAlt = 0;   // Current altitude position

// Pulse timing for debounce and stall detection
volatile unsigned long lastPulseAz = 0;
volatile unsigned long lastPulseAlt = 0;

// Milliseconds since the last accepted pulse on an axis, read race-free:
// the pulse timestamp first, then the clock, so an ISR landing between the
// two can only make the answer smaller. Every stall test must use this.
// The old form, "(now - lastPulseAz) > stallTimeoutMs" with `now` sampled at
// the top of the loop, wrapped to ~4e9 whenever a pulse's millis() ticked
// past `now` inside the loop body, and declared the axis at its limit in
// the middle of a regular full-speed pulse train with the motor at running
// current. About one pulse in a few thousand: 2026-09-08 (alt, +49 deg on
// a descent from the stow) and twice on 2026-09-10 (az, +159 and +156.5),
// each of which sent the re-approach into the switch at full speed and put
// the azimuth zero two or three pulses beyond the cut edge.
static inline unsigned long msSincePulse(volatile unsigned long &lastPulse) {
    unsigned long lp = lastPulse;
    unsigned long now = millis();
    return (now >= lp) ? (now - lp) : 0UL;
}

// Target position (in pulses)
int32_t targetAz = 0;
int32_t targetAlt = 0;

// Set true when a new target is commanded; cleared when motion starts.
// Prevents auto-correcting from stray pulses while idle (which can stall
// into limit switches).
bool newTargetAz = false;
bool newTargetAlt = false;

// Motion state per axis
typedef enum {
    MOTION_IDLE,        // Not moving
    MOTION_DRIVING,     // Moving toward target
    MOTION_STOPPING,    // Decelerating to reverse direction
    MOTION_FINISHING    // At target, ensuring reed switch ends in steady LOW
} MotionState;

MotionState motionStateAz = MOTION_IDLE;
MotionState motionStateAlt = MOTION_IDLE;

// Current direction for each axis (true = positive/increasing, false = negative/decreasing)
bool currentDirAz = true;   // true = East (HIGH), false = West (LOW)
bool currentDirAlt = true;  // true = Up (HIGH), false = Down (LOW)

// Azimuth backlash compensation: pulses to absorb after direction change
volatile int32_t azBacklashRemaining = 0;
bool lastDrivenDirAz = true;  // Last direction az actually drove (for backlash detection)

// Timing for ramps
unsigned long driveStartTimeAz = 0;
unsigned long driveStartTimeAlt = 0;
unsigned long stopStartTimeAz = 0;
unsigned long stopStartTimeAlt = 0;

// Speed tracking for smooth stopping (PWM value when stop was initiated)
int stopStartPwmAz = PWM_STOP;
int stopStartPwmAlt = PWM_STOP;

// Serial input buffers (one for each port)
char serialBuffer[64];
int serialIndex = 0;
char lastLineEndChar = 0;  // Track CR/LF to handle CRLF pairs

#if ENABLE_SERIAL1
char serial1Buffer[64];
int serial1Index = 0;
char lastLineEndChar1 = 0;  // Track CR/LF for Serial1
#endif

// Previous status string (for duplicate suppression on programming port)
char prevStatusLine[128] = "";

// True when current command was received over Serial1 (ESP32/controller),
// false when from Serial (programming port).
bool cmdFromSerial1 = false;

// The status line ends in a checksum, " *HH": the XOR of every character
// before the " *", in hex, as NMEA does (2026-10-02). It replaced the trailing
// "Cal:ON|OFF" field, which the controller used as its end-of-line marker -
// a truncated line failed to end with it. The checksum catches truncation the
// same way and also a corrupted byte mid-line, which the marker could not.
// The calibrator it reported was removed (issue #39).
static int appendStatusChecksum(char *buf, int pos, int size) {
    uint8_t x = 0;
    for (int i = 0; i < pos && buf[i]; i++) x ^= (uint8_t)buf[i];
    return pos + snprintf(buf + pos, size - pos, " *%02X", x);
}

// =============================================================================
// DUAL SERIAL OUTPUT HELPER
// =============================================================================

// Print to Programming Port (Serial) only
// Native USB (SerialUSB) is reserved for ESP32 bridge traffic

void printAll(const char* str) {
    Serial.print(str);
}

void printAllLn(const char* str) {
    Serial.println(str);
}

void printAllFloat(float val, int decimals) {
    Serial.print(val, decimals);
}

void printAllInt(int val) {
    Serial.print(val);
}

void printPrompt() {
    printAll("> ");
}

// =============================================================================
// CONFIGURATION MANAGEMENT
// =============================================================================

uint32_t calculateChecksum(const Config* c) {
    uint32_t sum = 0;
    const uint8_t* p = (const uint8_t*)c;
    // Sum all bytes except the checksum field itself
    for (size_t i = 0; i < sizeof(Config) - sizeof(uint32_t); i++) {
        sum += p[i];
    }
    return sum;
}

void loadDefaults() {
    cfg.magic = CONFIG_MAGIC;
    // Hardware limits (physical limit switches)
    cfg.altHwMin = DEFAULT_ALT_HW_MIN;
    cfg.altHwMax = DEFAULT_ALT_HW_MAX;
    cfg.azHwMin = DEFAULT_AZ_HW_MIN;
    cfg.azHwMax = DEFAULT_AZ_HW_MAX;
    // Software limits (operational, inside hardware limits)
    cfg.altMin = DEFAULT_ALT_MIN;
    cfg.altMax = DEFAULT_ALT_MAX;
    cfg.azMin = DEFAULT_AZ_MIN;
    cfg.azMax = DEFAULT_AZ_MAX;
    cfg.homeAlt = DEFAULT_HOME_ALT;
    cfg.homeAz = DEFAULT_HOME_AZ;
    cfg.rampUpMs = DEFAULT_RAMP_UP_MS;
    cfg.rampDownDeg = DEFAULT_RAMP_DOWN_DEG;
    cfg.stopRampMs = DEFAULT_STOP_RAMP_MS;
    cfg.currentLimit = DEFAULT_CURRENT_LIMIT;
    #ifdef SIMULATION_MODE
    cfg.stallTimeoutMs = SIM_STALL_TIMEOUT_MS;  // Faster stall detection in simulation
    #else
    cfg.stallTimeoutMs = DEFAULT_STALL_TIMEOUT;
    #endif
    cfg.debounceMs = DEFAULT_DEBOUNCE_MS;
    cfg.debounceAltMs = DEFAULT_DEBOUNCE_ALT_MS;
    cfg.backlashAzDeg = DEFAULT_BACKLASH_AZ;
    cfg.checksum = calculateChecksum(&cfg);
}

bool loadConfig() {
    // Read config from flash
    byte* p = flashStorage.readAddress(0);
    memcpy(&cfg, p, sizeof(Config));

    // Validate magic and checksum
    if (cfg.magic != CONFIG_MAGIC) {
        return false;
    }

    uint32_t expectedChecksum = calculateChecksum(&cfg);
    if (cfg.checksum != expectedChecksum) {
        return false;
    }

    return true;
}

void saveConfig() {
    cfg.magic = CONFIG_MAGIC;
    cfg.checksum = calculateChecksum(&cfg);

    // Write config to flash
    byte* data = (byte*)&cfg;
    for (size_t i = 0; i < sizeof(Config); i++) {
        flashStorage.write(i, data[i]);
    }
}

// Helper to get home offset in pulses (from limit / position 0)
int32_t getHomeAzOffsetPulses() {
    return (int32_t)(cfg.homeAz * PULSES_PER_DEGREE);
}

int32_t getHomeAltOffsetPulses() {
    return (int32_t)(cfg.homeAlt * PULSES_PER_DEGREE);
}

// Helper to get ramp down pulses from degrees
int32_t getRampDownPulses() {
    return (int32_t)(cfg.rampDownDeg * PULSES_PER_DEGREE);
}

// =============================================================================
// INTERRUPT SERVICE ROUTINES
// =============================================================================

// Runt-pulse filter: after the rising edge, the pin should remain HIGH for at
// least this many microseconds. Glitches shorter than this are ignored.
#define PULSE_MIN_WIDTH_US 1000

// Encoder statistics per drive, for the debounce-margin question (#32): the
// alt window (100 ms) sits only 28% under the pulse period at full speed
// (128 ms at 3.9 deg/s), so a gravity-assisted descent that runs faster
// rejects real pulses and the counter runs slow while the axis moves. These
// count what the ISR actually saw: pulses rejected by the window, the
// shortest interval it accepted (the true pulse period at speed), and the
// longest interval it rejected (how close a real pulse came to the window -
// near the window means a real pulse, near zero means contact bounce).
// Reset at each driveToLimits, printed with each limit line.
volatile uint32_t encRejectedAz = 0, encRejectedAlt = 0;
volatile unsigned long encMinAcceptedAz = 0, encMinAcceptedAlt = 0;  // 0 = none yet
volatile unsigned long encMaxRejectedAz = 0, encMaxRejectedAlt = 0;
volatile unsigned long encLastAcceptedAz = 0, encLastAcceptedAlt = 0; // interval of the latest accepted pulse: the speed at the stop

static void resetEncoderStats() {
    noInterrupts();
    encRejectedAz = encRejectedAlt = 0;
    encMinAcceptedAz = encMinAcceptedAlt = 0;
    encMaxRejectedAz = encMaxRejectedAlt = 0;
    encLastAcceptedAz = encLastAcceptedAlt = 0;
    interrupts();
}

static String encoderStats(bool alt) {
    uint32_t rej = alt ? encRejectedAlt : encRejectedAz;
    unsigned long minAcc = alt ? encMinAcceptedAlt : encMinAcceptedAz;
    unsigned long maxRej = alt ? encMaxRejectedAlt : encMaxRejectedAz;
    unsigned long last = alt ? encLastAcceptedAlt : encLastAcceptedAz;
    unsigned long window = alt ? cfg.debounceAltMs : cfg.debounceMs;
    return " [enc: rejected " + String(rej)
         + ", min accepted " + (minAcc ? String(minAcc) + " ms" : String("-"))
         + ", last accepted " + (last ? String(last) + " ms" : String("-"))
         + ", max rejected " + String(maxRej) + " ms"
         + ", window " + String(window) + " ms]";
}

void pulseAzISR() {
    // Reject runt pulses — confirm the pin is still HIGH after a brief delay
    delayMicroseconds(PULSE_MIN_WIDTH_US);
    if (digitalRead(PIN_PULSE_AZ) != HIGH) return;

    unsigned long now = millis();
    unsigned long interval = now - lastPulseAz;
    if (interval >= cfg.debounceMs) {
        if (azBacklashRemaining > 0) {
            // Absorb backlash pulse - motor is taking up gear slack
            azBacklashRemaining--;
        } else {
            // Determine direction from DIR pin state
            if (digitalRead(PIN_DIR_AZ) == AZ_DIR(HIGH)) {
                positionAz++;   // Moving East (increasing)
            } else {
                positionAz--;   // Moving West (decreasing)
            }
        }
        if (encMinAcceptedAz == 0 || interval < encMinAcceptedAz) encMinAcceptedAz = interval;
        encLastAcceptedAz = interval;
        lastPulseAz = now;  // Only update on pulses that pass debounce
    } else {
        encRejectedAz++;
        if (interval > encMaxRejectedAz) encMaxRejectedAz = interval;
    }
}

void pulseAltISR() {
    delayMicroseconds(PULSE_MIN_WIDTH_US);
    if (digitalRead(PIN_PULSE_ALT) != HIGH) return;

    unsigned long now = millis();
    unsigned long interval = now - lastPulseAlt;
    if (interval >= cfg.debounceAltMs) {
        // Determine direction from DIR pin state
        if (digitalRead(PIN_DIR_ALT) == ALT_DIR(HIGH)) {
            positionAlt++;  // Moving Up (increasing)
        } else {
            positionAlt--;  // Moving Down (decreasing)
        }
        if (encMinAcceptedAlt == 0 || interval < encMinAcceptedAlt) encMinAcceptedAlt = interval;
        encLastAcceptedAlt = interval;
        lastPulseAlt = now;  // Only update on pulses that pass debounce
    } else {
        encRejectedAlt++;
        if (interval > encMaxRejectedAlt) encMaxRejectedAlt = interval;
    }
}

// =============================================================================
// SIMULATION - Pulse Generation
// =============================================================================
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
void loop() {
    #if ESP_BRIDGE_ENABLED
    // Bridge Native USB <-> Serial1 (ESP32) - runs every loop, always active
    handleESPBridge();
    #endif

    // Update current filter every loop (100Hz at 10ms loop delay)
    updateFilteredCurrents();
    xtraceSample();

    // Safety checks (always run)
    runSafetyChecks();

    // Process serial commands
    processSerialInput();

    // Update motor control (if not in fault state)
    if (systemState != STATE_FAULT && systemState != STATE_HOMING) {
        updateMotion();
    }

    #ifdef SIMULATION_MODE
    simulatePulses();
    #endif

    // Output status only when something changes
    outputStatusIfChanged();

    delay(MAIN_LOOP_DELAY_MS);
}

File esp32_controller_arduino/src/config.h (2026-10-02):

// config.h - Configuration settings for SRT Controller
// Supports ESP32-S3 and WT32-ETH01

#ifndef CONFIG_H
#define CONFIG_H

// WiFi Access Point settings
#define WIFI_AP_SSID "SRT_Controller"
#define WIFI_AP_PASSWORD "radio1420"

// Network discovery name. The controller should be reachable as
// http://srt-controller.local/ on networks that support mDNS.
#define CONTROLLER_HOSTNAME "srt-controller"

// Network OTA updates. After one serial flash with this firmware installed,
// routine WT32 updates can be uploaded over Ethernet.
#define OTA_ENABLED 1
#define OTA_PORT 3232
#define OTA_PASSWORD "srt-ota-1420"

// WiFi connection timeout (seconds)
#define WIFI_CONNECT_TIMEOUT 15

// =============================================================================
// Board-specific pin configuration
// =============================================================================

#ifdef BOARD_WT32_ETH01
    // WT32-ETH01: Serial to Due via GPIO4/14
    // Note: GPIO32/33 labelled CFG/485_EN on RS-485 variants - avoid those
    // TX0/RX0 (GPIO1/3) reserved for programming - no need to disconnect Due
    #define DUE_UART_TX 4    // WT32 IO4 -> Due RX (pin 19)
    #define DUE_UART_RX 14   // WT32 IO14 <- Due TX (pin 18)

    // Ethernet PHY configuration (LAN8720) - pin numbers only
    // The actual PHY type constants are defined by ETH.h
    #define ETH_PHY_ADDR_CFG    1
    #define ETH_PHY_MDC_PIN     23
    #define ETH_PHY_MDIO_PIN    18
    #define ETH_PHY_POWER_PIN   16

    // Enable Ethernet support
    #define ETHERNET_ENABLED 1
#else
    // ESP32-S3 Super Mini: Serial to Due via GPIO5/6
    #define DUE_UART_TX 5    // ESP32-S3 GPIO -> Due RX (pin 19)
    #define DUE_UART_RX 6    // ESP32-S3 GPIO <- Due TX (pin 18)

    // No Ethernet on ESP32-S3 Super Mini
    #define ETHERNET_ENABLED 0
#endif

#define DUE_BAUD_RATE 115200

// Server ports
#define STELLARIUM_PORT 10001
#define WEB_PORT 80

// Observer location (Acre Road Observatory, Glasgow)
#define OBSERVER_LAT 55.902426
#define OBSERVER_LON -4.307865

// NTP server. Deliberately a public pool address rather than a local host, to
// keep hard-coded site addresses out of the firmware; under a private point-to-
// point link the observatory computer routes this out to the internet.
#define NTP_SERVER "pool.ntp.org"
// Numeric fallback, tried when the name cannot be resolved. DNS resolution has
// been observed to fail on this controller while routing is perfectly healthy:
// pointed at this address the clock syncs in under six seconds, pointed at the
// name it never syncs at all. time.cloudflare.com anycast; not a site-local
// address, so it does not tie the firmware to this observatory.
#define NTP_SERVER_FALLBACK "162.159.200.123"

// Ethernet static-IP fallback, used only if DHCP is turned off in the web UI.
// The controller runs on DHCP and its address is pinned by MAC on the host, so
// these are never applied in normal operation — but they are what the Static IP
// form is pre-filled with, so they must name the link the controller is actually
// on. They were left at a 192.168.1.x factory placeholder, which meant one tick
// of that box would have moved the controller off the link entirely, reachable
// only over the WiFi AP.
#define DEFAULT_ETH_STATIC_IP "192.168.50.120"
#define DEFAULT_ETH_GATEWAY   "192.168.50.1"
#define DEFAULT_ETH_SUBNET    "255.255.255.0"
#define DEFAULT_ETH_DNS       "192.168.50.1"

// Clock discipline. The lwIP SNTP client polls in the background at this
// interval; nothing blocks waiting for it. Five hours of drift is itself
// harmless - the warning exists to catch a failed sync *mechanism* within an
// observing session rather than days later.
#define NTP_SYNC_INTERVAL_MS 3600000UL  // re-sync every hour
#define CLOCK_STALE_WARN_S   18000UL    // warn after 5 h with no successful sync
#define NTP_RETRY_INTERVAL_MS 300000UL  // retry every 5 min while never synced

// Mount software limits (degrees)
#define MOUNT_AZ_MIN 2.0
#define MOUNT_AZ_MAX 350.0     // the azimuth cabling is strained beyond this (2026-10-01)
#define MOUNT_ALT_MIN 0.0
#define MOUNT_ALT_MAX 90.0

// Minimum TRUE altitude for a sky target to clear the local horizon and trees.
// This is a sky quantity and it belongs to the true frame: it is tested against
// the target's true altitude, before the pointing model converts it to drive
// coordinates. MOUNT_ALT_MIN above is a mechanical limit in the drive frame and
// is applied afterwards. The two used to be merged by taking whichever was
// larger, which quietly reinterpreted a mechanical stop as a sky horizon (and
// vice versa) and made neither testable on its own.
#define TRACKING_HORIZON_ALT 10.0

// Acquisition floor for the galactic-plane target (degrees). Where tracking is
// allowed to START; the target is then followed down as it sets, until the
// ordinary observing horizon above parks the dish. High on purpose - see
// getGalacticPlaneTrackingTarget() in coordinates.h.
#define GALACTIC_PLANE_MIN_ALT 45.0

// Stow position (degrees) - where the dish parks when idle or when its target
// sets. Zenith, facing south: straight up sheds rain and snow and presents the
// smallest profile to the wind.
//
// These are DRIVE coordinates, and they are the one sky-facing-looking setting
// that is not in the true frame. Parking is a mechanical act - "leave the mount
// here" - not an observation, so the pointing model is deliberately bypassed
// on the stow path. At the zenith that distinction is not academic: azimuth is
// degenerate there, every azimuth points at the same piece of sky, and the
// model's azimuth term carries tan(alt), so it asks for a 50-degree correction
// that would move the beam by exactly nothing. Through the model this position
// parks at drive azimuth 170; bypassing it, the mount rests where it is told.
//
// Still not to be confused with the Due's cfg.homeAlt/homeAz, which are also
// drive coordinates but mean the encoder origin - what the limit-switch stall
// corresponds to - rather than a place to park.
#define STOW_ALT 90.0
#define STOW_AZ 180.0

// Position deadband (degrees)
#define POSITION_DEADBAND 0.25

// Credentials file path
#define WIFI_CREDS_FILE "/wifi_creds.txt"

#endif // CONFIG_H

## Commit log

2026-03-11 Initial commit: SRT Drive Controller firmware
    Arduino Due firmware for controlling the alt-azimuth drive system
    of the Small Radio Telescope at Acre Road Observatory.
    Features:
    - Automatic homing sequence
    - Smooth motion with acceleration/deceleration ramps
    - Serial command interface (USB + UART)
    - Persistent configuration in flash
    - Overcurrent and stall protection
    [config.h, main.cpp]
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2026-03-13 Add two-tier limit system and tracking wait states
    - Arduino Due: Add hardware limits (physical switches) separate from
    software limits (operational, 2 deg inside hardware). Commands that
    exceed software limits + 4 deg tolerance are rejected.
    - ESP32: Add waiting states for below-horizon targets (parks at home)
    and circumpolar wrap-around (waits for target to reappear in limits).
    Web UI shows waiting status in orange.
    - Update observer location to precise Acre Road coordinates.
    [config.h, main.cpp]
2026-03-13 Add position bounds safety check and tracking deadband
    Arduino Due:
    - Add position bounds check: faults if position exceeds hardware
    limits by more than 5 degrees (catches encoder errors, broken stops)
    - New faults: FAULT_AZ_POSITION_BOUNDS, FAULT_ALT_POSITION_BOUNDS
    ESP32:
    - Add 0.25 degree position deadband to prevent motor hunting
    - Only send commands when target moves more than deadband threshold
    [main.cpp]
2026-03-13 Add stall detection to homing phase 2
    Previously, if motors weren't connected, homing would complete phase 1
    (finding limits via stall timeout) but hang forever in phase 2 (moving
    to home position) because no encoder pulses would arrive.
    Now phase 2 also checks for stall timeout and aborts with a clear
    error message if motors don't respond.
    [main.cpp]
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2026-03-15 Add Arduino/PlatformIO ESP32-S3 controller, rename MicroPython version
    New esp32_controller_arduino replaces MicroPython with C++ for better
    performance and reliability:
    - AsyncWebServer with embedded HTML for fast page loads
    - AsyncTCP-based Stellarium telescope protocol (port 10001)
    - WiFi AP+STA mode with NVS credential storage
    - NTP time sync with browser fallback
    - Celestial tracking: Sun, Moon, RA/Dec, Galactic coordinates
    - Serial communication with Arduino Due motor controller
    - 4MB flash partition scheme for ESP32-S3 Super Mini
    Renamed esp32_controller to esp32_controller_micropython for clarity.
    [partitions.csv]
2026-03-15 Add runtime settings with NVS persistence and web UI
    New Settings tab allows configuring without recompilation:
    - Observer location (latitude/longitude)
    - Software limits (alt/az min/max)
    - Home position
    - Update tolerance (tracking deadband)
    - WiFi AP SSID and password
    - Page name (display title)
    Settings persist in flash via ESP32 Preferences/NVS.
    Defaults from config.h used on first boot.
    Also fixed route ordering for /settings/* endpoints.
    [main.cpp, settings.cpp, stellarium.cpp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]
2026-03-15 Fix USB CDC blocking when no terminal connected
    Wrap debug Serial.print calls in tracking loop with DBG() macro
    that checks if USB CDC is connected before printing. This allows
    the ESP32 to run properly without a serial monitor attached.
    [main.cpp]
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2026-03-18 Add ESP32 bridge to Due firmware for WT32-ETH01 programming
    Due firmware changes:
    - Native USB (SerialUSB) acts as transparent USB-to-serial bridge
    - Serial1 <-> SerialUSB passthrough runs continuously in loop()
    - ESPBOOT command puts ESP32 in download mode via GPIO0/EN control
    - ESPRESET command resets ESP32 to normal operation
    - Bridge is always active, no mode switching needed
    Hardware: Due pins 2,3 control ESP32 GPIO0,EN for boot mode
    Documentation:
    - Add WT32_ETH01_MIGRATION.md with complete migration guide
    - Dual-USB architecture diagram
    - Two programming methods: physical buttons or ESPBOOT command
    - Explains transparent bridge and why auto-reset isn't available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
    [main.cpp]
2026-03-23 Simplify ESP32 bridge to monitoring only, program externally
    - Remove ESPBOOT/ESPRESET commands and GPIO0/EN pin control
    - Simplify ESP32 bridge to serial monitoring passthrough only
    - Fix simulation mode to pass through ESP bridge pin operations
    ESP32 changes:
    - Add WT32-ETH01 environment with native Ethernet support
    - Add BOARD_WT32_ETH01/BOARD_ESP32S3 conditional compilation
    - Add Ethernet PHY configuration for LAN8720
    - Update WT32_ETH01_MIGRATION.md for external USB-TTL programming
    - Remove Due-based boot mode control sections
    - Clarify TX0/RX0 vs TXD/RXD pin usage
    Programming is now done via external USB-TTL adapter with manual
    IO0/EN buttons, wh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
    [config.h, main.cpp, web_server.cpp]
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2026-03-27 Add Ethernet DHCP/static IP configuration via web interface
    - DHCP mode (default) or static IP configuration
    - Configurable IP address, gateway, subnet mask, and DNS
    - Settings stored in NVS and persist across reboots
    - Web UI in Network tab with DHCP/Static radio buttons
    - API endpoint /eth/save for programmatic configuration
    Changes:
    - settings.h/cpp: Add ethUseDHCP, ethStaticIP, ethGateway,
    ethSubnet, ethDNS fields with NVS persistence
    - main.cpp: Apply static IP config via ETH.config() on boot
    - web_server.cpp: Add /eth/save endpoint, include Ethernet
    settings in /wifi/status response
    - index_html.h: Add Ethernet configuration UI with
    DHCP/Static toggle and input fields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
    [main.cpp, settings.cpp, web_server.cpp]
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2026-03-27 Add pointing offset for scanning/mapping applications
    Allows offsetting the antenna by dAlt/dAz from the nominal target
    position. Useful for raster scanning around a source.
    - Offset applied on top of tracking position
    - Clamped to mount limits
    - Displayed in tracking status when non-zero
    - API: /offset?alt=X&az=Y to set, /offset/clear to reset
    UI adds "Pointing Offset (Scanning)" box with:
    - dAlt/dAz input fields (-45 to +45 degrees)
    - Apply Offset and Clear buttons
    - Current offset display
    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
    [main.cpp, state.h, web_server.cpp]
2026-03-27 Add calibrator control via Due GPIO and web interface
    Adds control for a noise calibrator used in system calibration.
    Due firmware:
    - PIN_CALIBRATOR (pin 26) controls calibrator on/off
    - CAL command: CAL ON, CAL OFF, or CAL to toggle
    - Calibrator state shown in status output (Cal:ON/OFF)
    ESP32 firmware:
    - Parses Cal:ON/OFF from Due status
    - /calibrator?on=1|0 API endpoint
    - /status includes calibrator state
    - Web UI button in Control tab (green when ON)
    [config.h, main.cpp, srt_serial.cpp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]
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2026-03-27 Add ESP32 diagnostic messages to serial monitor
    - New logESP() method for ESP32 internal events
    - Log tracking state changes (enabled, stopped, horizon, az limits)
    - Log NTP sync success/failure
    - Log Stellarium connect/disconnect and goto commands
    - Log browser time sync
    - ESP messages shown in amber color in web UI
    [main.cpp, srt_serial.cpp, stellarium.cpp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]
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2026-03-27 Fix native unit test configuration
    - Update build_src_filter to properly exclude ESP32-only files
    - Add test_build_src = yes to include source in test builds
    - Fix test_altaz_horizon_north expectation (was using wrong formula)
    All 15 coordinate tests now pass.
    [wt32_eth01_enclosure.scad, wt32_eth01_enclosure.stl, wt32_eth01_enclosure_base.stl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]
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2026-03-28 Fix ESP32-Due serial communication and add WiFi power control
    - Fix Due firmware to process commands from Serial1 when ESP bridge enabled
    - Fix Due firmware to send status responses to Serial1 (ESP32)
    - Fix position rounding: use round() instead of truncation for 0.5deg resolution
    - Add WiFi power control: disable WiFi to save ~100mA when using Ethernet
    - Add /wifi/power API endpoint and web UI toggle button
    - Update all documentation to reflect IO4/IO14 pins and new features
    [config.h, main.cpp, settings.cpp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]
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2026-03-29 Add sun scan pointing calibration, fix current sensing, Native USB docs
    - Add sun_scan.py: nxn raster scan around the sun with 2D Gaussian fit
    to determine pointing errors (alt/az correction)
    - Integrate sun scan into web scheduler as a new tab with live progress,
    results display, and generated image
    - Fix current sensor calibration: 44mV/A sensitivity, 3.3V ADC reference,
    1.65V zero-current offset (bipolar)
    - Add IIR low-pass filter for current display (~1s settling time),
    raw readings retained for safety fault detection
    - Simulation mode now reads real current sensor hardware
    - Native USB (SerialUSB) reserved for ESP32 bridge traffic only
    - Document Native USB DTR requirement (use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
    [config.h, main.cpp, settings.cpp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]
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2026-03-31 First physical drive test: fix az direction, current sensing, debounce, stall detection
    Fixes from first test with physical hardware:
    - Invert azimuth motor direction (AZ_DIR_INVERT) - motor was wired in reverse
    - Negate Iaz current reading in status output
    - Set default home position to (0, 0)
    - Increase encoder debounce to 200ms (configurable via SET DEBOUNCE)
    - Fix stall detection false positives by requiring drive time >= timeout
    - Fix current readings during homing (updateFilteredCurrents in homing loops)
    - Suppress duplicate status lines on programming port (ignore current-only changes)
    - RESET command clears fault without automatic re-home
    - Minimum PWM speed set to 100
    Co-Authored-B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
    [config.h, main.cpp]
2026-03-31 Add azimuth backlash compensation and homing backlash take-up
    - Add configurable BACKLASH parameter (default 2.0 deg) for azimuth gear backlash
    - On az direction reversal, absorb backlash pulses in ISR before counting position
    - Homing sequence drives forward after limit to take up backlash before zeroing
    - Tune via SET BACKLASH <deg>, persist with SAVE
    [config.h, main.cpp]
2026-04-07 Fix debounce overcounting, prevent idle auto-correction, add raw count display
    - ISR debounce timer now only resets on counted pulses (not every edge),
    fixing total pulse loss when motor speed approaches debounce window
    - Add newTargetAz/newTargetAlt flags so motors only drive on commanded
    slews, not to auto-correct stray drift (which could stall into limits)
    - Backlash take-up during homing uses PWM_FULL_SPEED to break free quickly
    - Add raw azimuth pulse count (AzRaw) to status output for diagnosis
    - Update default DEBOUNCE to 50ms and BACKLASH to 0 deg
    [config.h, main.cpp]
2026-04-07 Multi-phase homing, ALT direction invert, status routing, current offset tracking
    Drive firmware:
    - Homing now has 3 phases: ramped drive to limit, back off 5 deg, slow re-approach
    - backOffFromLimits and driveToLimits both ramp up using normal RAMPUP profile
    - Add ALT_DIR_INVERT flag (mirrors AZ_DIR_INVERT) - alt motor wired in reverse
    - Persist driver fault flags for 5 cycles before reporting (suppress transients)
    - Snap to hardware limit on stall when driving negative near limit (no fault)
    - Use filtered current for overcurrent check (ignore brief spikes)
    - Continuously track current sensor zero offset while motor is idle
    - STATUS over Serial1 (controller) responds only to Serial1, doesn'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
    [config.h, main.cpp]
2026-05-12 Per-axis debounce, MOTION_FINISHING, runt-pulse filter, RA/Dec/Galactic display
    - Trigger encoder ISRs on RISING edge instead of FALLING.
    - Reject runt pulses in the ISR by re-reading the pin 1 ms after the
    rising-edge interrupt; if the pin has returned LOW the pulse was a
    glitch and is discarded.
    - Add MOTION_FINISHING state: on reaching the target, the motor is
    stopped, allowed to coast for 50 ms, then the pulse pin is sampled
    10 times (~1 ms total). If all samples are LOW the slew completes;
    otherwise the motor drives at PWM_MIN_SPEED until the reed switch
    settles in a steady-closed state. Guarantees a consistent end-of-
    slew reed-switch state. 2 s safety tim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
    [config.h, main.cpp, web_server.cpp]
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2026-07-08 Improve controller tracking controls and status
    Add controller endpoints and web UI controls for axis-only tracking, movement stop holds, stop-all, homing, and fault reset.
    Expose fault-active and axis-mode state in JSON status responses, and preserve axis-only tracking when commands arrive from Stellarium.
    Relax status-line parsing so slewing target readbacks with repeated Alt/Az fields are still accepted.
    [srt_serial.cpp, stellarium.cpp, web_server.cpp]
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2026-08-04 Register specific web routes before their prefixes
    ESPAsyncWebServer matches a handler when the request URL equals its URI
    or starts with that URI plus a slash, and the first registered match
    wins. "/goto" was registered before "/goto/galactic", so a galactic goto
    was handled by the RA/Dec route instead. That route reads absent "ra"
    and "dec" args as 0, evaluated RA 0h Dec 0 against the tracking horizon
    and rejected the slew with a spurious "target below horizon" altitude,
    or slewed to the wrong sky position when RA 0/Dec 0 happened to be up.
    "/offset" shadowed "/offset/clear" the same way, making the clear button
    a no-op that left the pointing offset in place.
    Move both specific routes ah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
    [web_server.cpp]
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2026-08-19 Sync the controller clock for real, and re-sync it hourly
    The controller was 1h30m03s slow while reporting "source":"NTP". syncTimeNTP()
    waited for the clock to become merely *plausible* (later than 2001), not for
    SNTP to have set it. A soft reset - an OTA update, a watchdog reboot - does not
    reset the RTC domain, so time(nullptr) returned a plausible value on the first
    iteration and the function declared success although NTP never completed. Since
    this board is updated over OTA, the clock was only ever genuinely set on a cold
    power cycle.
    Success is now declared only by the SNTP notification callback, which fires when
    the clock has actually been set, and esp_sntp_set_sync_interval() re-syn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
    [config.h, main.cpp, state.h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]
2026-08-19 Consume the newTarget flag on sight, not only when it moves
    newTargetAz/newTargetAlt guard the IDLE->DRIVING transition so the controller
    cannot chase stray encoder pulses into a limit switch. They were set on every
    command but cleared only inside the "remaining > 0" branch of updateAxisMotion,
    so a command whose rounded target equals the current position left the flag
    latched true indefinitely, and the next stray pulse then started an uncommanded
    drive - precisely what the guard exists to prevent.
    executeDrive() rounds targets to the nearest pulse, and the controller's send
    deadband was exactly half the 0.5 degree quantum, so this was happening about
    half the time already. It becomes total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
    [main.cpp]
2026-08-19 Lock the state shared between async_tcp and loopTask
    ESPAsyncWebServer handlers and the Stellarium AsyncTCP callbacks run on the
    async_tcp task; tracking and Due serial polling run on loopTask. There was no
    mutex anywhere in the firmware, and four review findings share that one cause.
    One recursive mutex covers all of them (sync.h). A single lock has no ordering
    to get wrong, and recursion lets a locked method call another - sendTarget()
    calling logMessage() is exactly that.
    C1: heap Strings reassigned on one task while copied on the other. The status
    strings and the log ring buffer are the constantly-exercised case - logMessage()
    rewrites entries at over 2 Hz while /serial/log iterates th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
    [main.cpp, srt_serial.cpp, stellarium.cpp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]
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2026-08-19 Stop the WiFi handlers blocking the network task
    C3: /wifi/scan bracketed a four-second blocking scan with
    esp_task_wdt_delete(NULL) / esp_task_wdt_add(NULL). Those two lines were the
    real bug. The delete failed because async_tcp was never subscribed to the task
    watchdog, and the add then subscribed it permanently - a task that blocks in
    queue waits and never resets the watchdog, so from the first scan onwards the
    controller would report "Task watchdog got triggered" every watchdog period,
    and reboot outright with TWDT panic enabled. Nothing there needed the watchdog;
    both lines are gone.
    The scan is now asynchronous: /wifi/scan starts one and reports "running", and
    the UI polls. Measured o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
    [config.h, main.cpp, web_server.cpp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]
2026-08-19 Fall back to a numeric NTP server when DNS fails
    The controller stopped syncing its clock entirely: sync_count stayed at zero
    across soft resets, a cold power cycle, a forced re-init and a full WiFi radio
    restart, while HTTP over Ethernet stayed perfectly healthy throughout.
    Pointing NTP_SERVER at a literal address made it sync in under six seconds,
    which isolates it: routing and outbound UDP/123 are fine, and so is the SNTP
    code. The controller simply cannot resolve pool.ntp.org, while this host on the
    same subnet resolves it without trouble.
    configTime() takes up to three servers, so the name stays first and a numeric
    address sits behind it. A DNS failure now degrades to a working clock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
    [config.h, main.cpp]
2026-08-19 Stop /wifi/power freezing the network stack
    Disabling WiFi from the web interface left it apparently impossible to turn
    back on. The enable path ran WiFiManager::startup() directly in the request
    handler, on async_tcp: a mode change, an AP start with its settling delays, and
    then a blocking station connect loop of up to WIFI_CONNECT_TIMEOUT. Measured on
    the hardware, the reply to /wifi/power?enable=1 had still not arrived after 60
    seconds - though the radio did come back. So the operation was succeeding while
    the browser reported it as failed, and the whole web UI was frozen meanwhile.
    The handler now records the wanted state, queues the change and answers
    immediately; loopTask actions it.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
    [main.cpp, web_server.cpp, wifi_manager.cpp]
2026-08-19 Hold the pointing calibration on the controller, in explicit frames
    Issue #8. The fitted pointing model used to reach the controller by two side
    channels, and both were abuses of fields that mean something else. The mount
    tilt went across as an "effective" observer latitude and longitude - exact
    mathematically, since a latitude shift reproduces a north tilt, but it left the
    web UI reporting a location the telescope is not at. The zero-point offsets went
    to /offset, the same pair the front page exposes for scanning, so calibration
    and operator intent shared one variable and any use of those boxes destroyed the
    calibration. Worse, that half lived in RAM only. Measured on 2026-08-19, the
    azimut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
    [config.h, main.cpp, pointing.cpp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]
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2026-08-19 Keep a DNS resolver on the controller
    The controller could not resolve names, so NTP only worked through the numeric
    fallback added in c889f61 and anything else resolving a name failed silently.
    lwIP's resolver list is process-wide rather than per-netif, and bringing the
    softAP up inside wifiManager.startup() clears it. A boot trace added to /network
    measures this rather than assuming it: dns_after_eth is the address DHCP
    supplied, dns_after_wifi is 0.0.0.0. It is not a one-off at startup either --
    counting the repairs shows it cleared again roughly every 2.5-3 seconds,
    indefinitely.
    The effect is sharper than a slow lookup. With no server configured
    dns_gethostbyname() fails immediately w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
    [main.cpp, web_server.cpp]
2026-08-19 Clear out the addresses left over from the old network
    A sweep for IP literals after the move to the private link (#10).
    The one that mattered was the Ethernet static-IP fallback, still at a
    192.168.1.x factory placeholder in settings.cpp and in the web UI's form
    placeholders. The controller runs on DHCP so it was inert, but it is what the
    Static IP form is pre-filled with: one tick of that box and a save would have
    moved the controller off the link entirely, reachable only over the WiFi AP.
    Now the link's own values, and defined once in config.h -- they were written
    twice each, as the defaults and again as the NVS getString() fallbacks, which is
    the kind of pair that drifts. The stored val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
    [config.h, settings.cpp]
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2026-08-19 Bring the technical article up to date, and add the science behind it
    The article had drifted a long way from the code. It documented a
    2.5 V/66 mV/A current sensor that is 1.65 V/44 mV/A, a 15 ms encoder
    debounce that is 50 and 100 ms, a PWM floor of 220 that is 100, a home
    azimuth of 180 that is 0, a single-phase homing sequence that has been
    three-phase for some time, and W5500 SPI Ethernet on a board with a
    LAN8720 PHY. All of that is corrected against the source.
    Four subsystems were missing entirely and are now described: the
    pointing model and its Sun-scan calibration, with the transform, the
    design matrix, the weighted fit and the quality gates; the private
    Ethernet link to the cont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
    [config.h]
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2026-08-21 Model the azimuth encoder scale error
    Replaces the per-session drift term added in 15af002. That term described the
    2026-08-20 residuals well enough, but as a rate it was the wrong object: it
    could not be sent to the controller, could not pool across days, and carried a
    caveat that a single solar day cannot tell a drift in time from a scale error
    because azimuth and time run together at 99.8% correlation.
    It is a scaling between measured and true drive azimuth. The reported azimuth
    is a count of encoder pulses, and if a pulse is not exactly half a degree the
    error grows with distance from the encoder zero. That is a static property of
    the drive: it pools across observing days, it is testabl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
    [pointing.cpp, pointing.h]
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2026-08-27 Due prints the encoder error at the homing stop; scheduler reads it there (issue #24)
    The counter at the stop is the net encoder error since the last homing (the
    stop is the true zero), and homing overwrote it with 0 unseen. driveToLimits
    now prints it on the limit line - "Homing: Azimuth limit reached at -3 pulses
    (-1.50 deg)" - first approach the accumulated error, re-approach the
    repeatability. The prefix is unchanged, so anything matching it still does.
    _homing_counters reads the number from the line when present, falling back to
    the preceding status-line scrape for firmware that predates it; that scrape
    failed on 2026-08-27 when an 8 s homing rolled the lines out of the 30-line
    serial b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
    [main.cpp]
2026-08-27 Homing error reaches the scheduler: Due sends it on Serial1, ESP32 latches it on /status (issue #24)
    The Due prints the counter at each homing stop, but printAll* go only to the
    USB port - the controller is on Serial1 - so the number never reached it, and
    the ESP32's read loop dropped the line as a non-status line anyway. Now the
    Due sends the limit lines and the phase markers to Serial1 too; the ESP32
    recognises them, parses the pulses/deg, and latches first-approach (the count
    error since the last homing) and re-approach (repeatability) per axis,
    exposing them as /status last_homing - which survives the status flood that
    scrolls the serial log. The scheduler reads last_homing, falling back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
    [main.cpp, srt_serial.cpp, web_server.cpp]
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
